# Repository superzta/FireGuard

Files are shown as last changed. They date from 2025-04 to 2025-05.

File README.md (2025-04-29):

# FireGuard: Automated Fire Detection and Monitoring System

FireGuard is an intelligent fire detection and monitoring system designed to proactively identify fire hazards using thermal imaging technology and provide real-time alerts through a web interface.

## System Overview

FireGuard consists of three main components:
- **Hardware**: An embedded system built on AVR microcontroller with thermal imaging camera, stepper motors for scanning, and other sensors
- **Firmware**: C code running on the AVR microcontroller
- **Web Interface**: Python Flask server and responsive web UI for monitoring and control

## System Features

- **360° Thermal Scanning**: Automated patrol mode that continuously scans the environment
- **High-Precision Fire Detection**: Uses the MLX90640 thermal imaging sensor to detect heat signatures
- **Real-time Monitoring**: Web interface displays temperature data and fire detection status
- **Automatic Targeting**: When a potential fire is detected, the system locks onto the target for monitoring
- **Distance Measurement**: Uses ultrasonic sensor to measure distance to the fire
- **Alert System**: Visual and audible alerts through LCD display and buzzer
- **Remote Control**: Web interface allows remote testing and system reset

## Hardware Components

### Sensors
- **MLX90640 Thermal Camera**: 32x24 IR array thermal imaging sensor (I²C)
- **HC-SR04 Ultrasonic Sensor**: Measures distance to fire
- **16x2 LCD Display**: Provides status information

### Actuators
- **Bipolar Stepper Motors (x2)**: For horizontal and vertical scanning movements
- **Servo Motor**: For fine adjustment of thermal camera position
- **Buzzer**: For audible fire alerts

### Microcontroller
- **AVR ATmega328P**: Main processing unit running at 7.3728MHz

### Connectivity
- **UART-to-USB Converter**: For communication with the web interface (230400 baud)

## Circuit Connections

### MLX90640 Thermal Camera
- SDA → PC4 (AVR I²C Data)
- SCL → PC5 (AVR I²C Clock)
- VCC → 3.3V
- GND → GND

### Stepper Motors (using EasyDriver)
- STEP_PIN_BTM → PC1 (Bottom stepper step control)
- STEP_PIN_TOP → PC2 (Top stepper step control)
- DIR_PIN → PC3 (Direction control for both steppers)
- VCC → 5V
- GND → GND

### Ultrasonic Sensor (HC-SR04)
- TRIG → PD6
- ECHO → PD7
- VCC → 5V
- GND → GND

### LCD Display (16x2)
- RS → PB0
- E → PB1
- D4 → PB2
- D5 → PB3
- D6 → PB4
- D7 → PB5
- VCC → 5V
- GND → GND

### Buzzer
- Signal → PD5
- GND → GND

### UART Connection
- TX → PD1
- RX → PD0
- Connected to computer via USB-to-UART adapter

## Software Architecture

### Firmware (AVR C)
- **FireGuard.c**: Main program logic
- **I2C.c/h**: Communication with MLX90640 thermal camera
- **stepper.c/h**: Stepper motor control for scanning
- **servo.c/h**: Servo motor control for fine positioning
- **ultrasonic.c/h**: Distance measurement
- **buzzer.c/h**: Alert system
- **lcd.c/h**: Display interface

### Web Interface
- **server.py**: Flask server that handles serial communication and API endpoints
- **FireGuard.html**: Responsive web UI with real-time data visualization
- **assets/**: CSS, JavaScript, and image resources

## Installation and Setup

### Firmware
1. Connect the AVR programmer to your computer
2. Navigate to the Firmware directory
3. Compile and upload using the included Makefile:
   ```bash
   cd FireGuard/Firmware/src
   make
   make flash
   ```

### Web Interface
1. Install Python 3.7 or higher
2. Install required packages:
   ```bash
   cd FireGuard/App
   pip install -r requirements.txt
   ```
3. Connect the FireGuard hardware via USB
4. Run the server:
   ```bash
   python server.py
   ```
5. Open a web browser and navigate to http://localhost:3000

## Troubleshooting

### Serial Connection Issues
- The default serial port is `/dev/cu.usbserial-A101167E`. If your system uses a different port, modify the `specific_port` variable in `server.py`
- Ensure the baud rate is set to 230400
- Check USB connections and drivers

### Temperature Sensor Issues
- The MLX90640 requires a warm-up period of approximately 10 seconds
- Ensure proper I²C connections and address (0x33)

### Motor Movement Issues
- Check stepper motor connections and power supply
- Verify the EasyDriver configuration (microstepping, current limiting)

## Future Enhancements

- Integration with smart home systems (HomeKit, Google Home)
- Cloud connectivity for remote monitoring
- Machine learning for improved fire detection accuracy
- Automatic fire suppression capabilities

## License

This project is licensed under the MIT License - see the LICENSE file for details.

## Contributors
- Owen Zeng
- Leikhang Xiong
- Robert Zhang

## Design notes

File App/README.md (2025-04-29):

# FireGuard Web Interface

This web application provides a user interface for the FireGuard fire detection system. It connects to the FireGuard hardware via serial communication and displays real-time fire detection data.

## Features

- Real-time monitoring of fire detection status
- Temperature data visualization with heat map
- Fire alerts with detailed information
- Remote system test and reset capabilities

## Prerequisites

- Python 3.7 or higher
- FireGuard hardware with firmware installed
- USB connection to the FireGuard device

## Installation

### Using the Setup Scripts (Recommended)

#### On macOS/Linux:

```bash
cd /path/to/FireGuard/App
chmod +x setup.sh
./setup.sh
```

#### On Windows:

```cmd
cd \path\to\FireGuard\App
setup.bat
```

### Manual Installation

1. Create a virtual environment:

```bash
# macOS/Linux
python3 -m venv venv
source venv/bin/activate

# Windows
python -m venv venv
venv\Scripts\activate
```

2. Install the required packages:

```bash
pip install -r requirements.txt
```

## Running the Application

1. Make sure the FireGuard hardware is connected to your computer via USB.

2. Activate the virtual environment (if not already activated):

```bash
# macOS/Linux
source venv/bin/activate

# Windows
venv\Scripts\activate
```

3. Run the server:

```bash
python server.py
```

4. Open a web browser and go to http://localhost:3000

## Usage

The web interface automatically connects to the FireGuard hardware when started. It will display:

- **All Clear**: When no fire is detected
- **Fire Alert**: When a fire is detected, showing the temperature matrix as a heat map
- **Fire Extinguished**: When a fire has been detected and subsequently extinguished

### Controls

- **Run Test**: Simulates a fire detection event (useful for testing without actual fire)
- **System Check**: Performs a system self-test
- **Emergency Override**: For manually controlling the system during a fire event
- **Reset System**: Resets the system after a fire has been extinguished

### Running Without Hardware

For testing and demonstration purposes, you can:

1. Start the Python server without hardware connected - it will provide simulated data through the test endpoint
2. Use the "Run Test" button to simulate a fire detection event

## Troubleshooting

If the web interface shows "Disconnected" in the status indicator:

1. Make sure the FireGuard hardware is properly connected via USB
2. Check that the correct serial port is being detected (the server prints this information on startup)
3. Try manually specifying your serial port by editing the `specific_port` variable in `server.py`
4. Restart the server with the hardware connected
5. If problems persist, check the Arduino IDE's serial monitor to verify the hardware is working correctly

## Developer Information

- The server runs on Flask and communicates with the web interface via JSON API endpoints at port 3000
- Real-time updates are implemented using AJAX polling
- Temperature matrix visualization uses CSS grid and dynamic color mapping

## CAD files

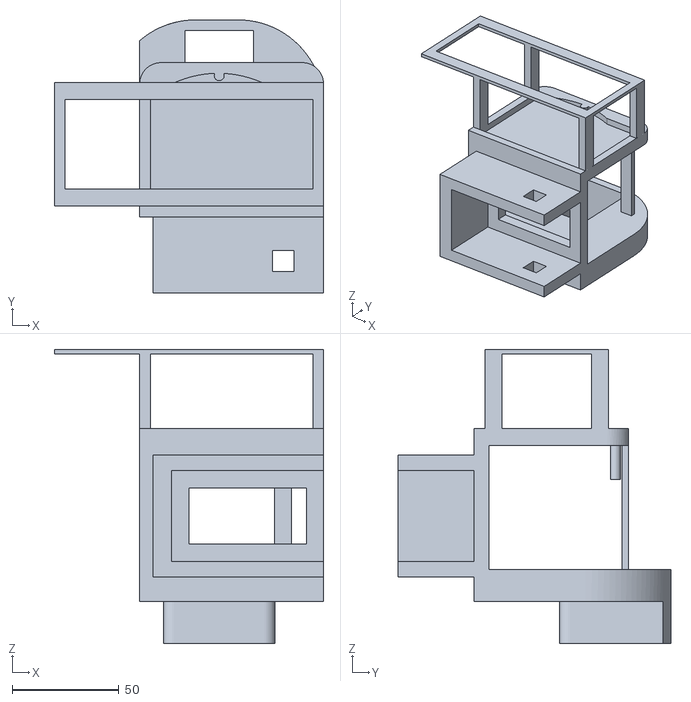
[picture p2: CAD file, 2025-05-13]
CAD/launcher_turret_draft1 v59.stl
126.1 x 127.9 x 137.7

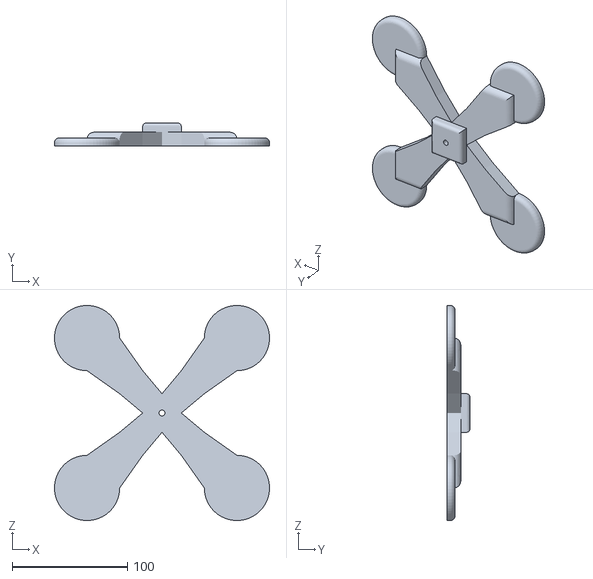
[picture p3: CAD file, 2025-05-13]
CAD/launcher_base_draft1 v13.stl
186.5 x 20.0 x 186.5

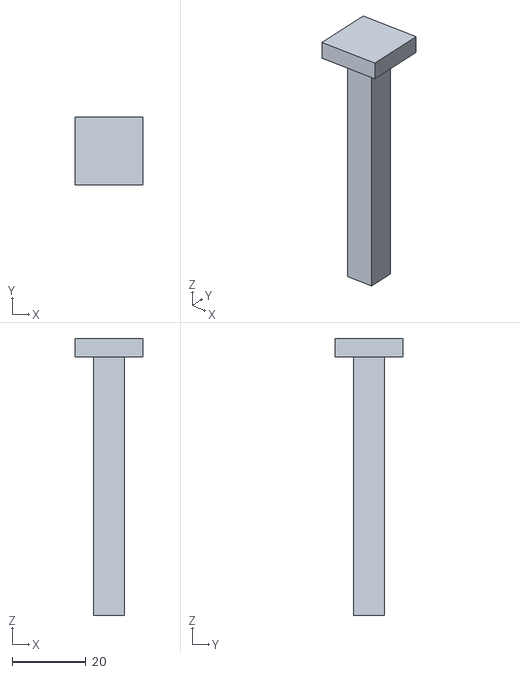
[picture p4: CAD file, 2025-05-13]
CAD/launcher_pin v2.stl
18.5 x 18.5 x 75.0

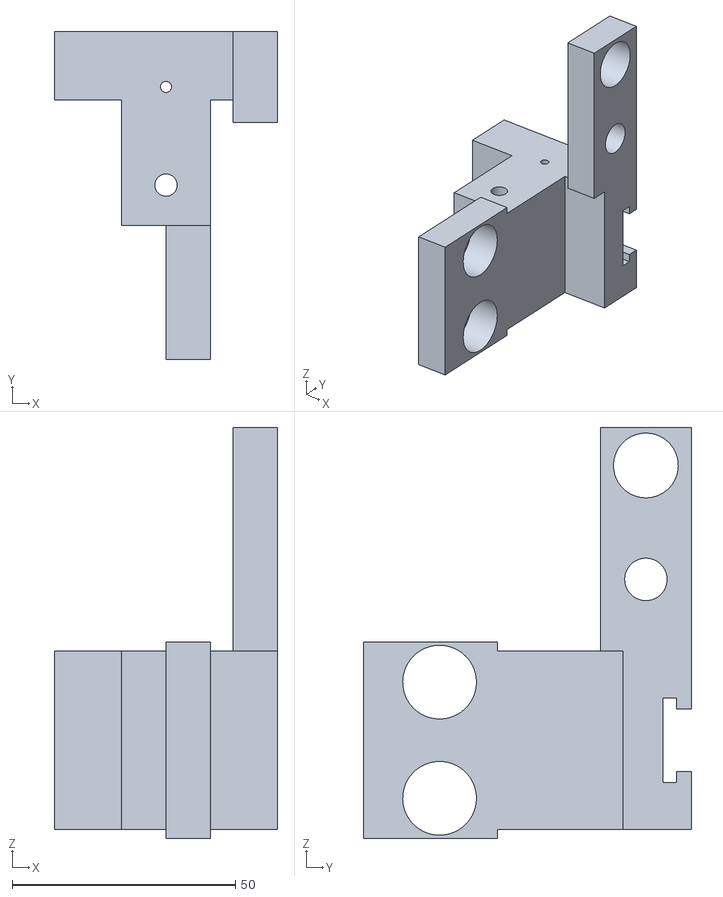
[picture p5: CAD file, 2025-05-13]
CAD/Launcher_mount_draft1 v21.stl
50.0 x 73.4 x 92.0

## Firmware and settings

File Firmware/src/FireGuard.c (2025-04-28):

#include <avr/io.h>
#include <util/delay.h>
#include <stdlib.h>
#include <stdio.h>
#include <avr/wdt.h>
#include <stdint.h>
#include <stdbool.h>

#include "I2C.h"
#include "stepper.h"
#include "servo.h"
#include "ultrasonic.h"
#include "buzzer.h"
#include "lcd.h"

#ifndef F_CPU
#define F_CPU 7372800UL
#endif

#define BAUD_RATE 230400

// Scanning motion parameters - easily changeable
#define SCAN_RANGE_STEPS 800   // 120 degrees of motion (approximately)
#define STEPS_PER_CHECK 20     // Check temperature every 20 steps
#define MOTOR_STEP_DELAY 10    // Milliseconds between steps to control speed

// Threshold temperature for fire detection (in centidegrees)
#define FIRE_THRESHOLD 5000  // 50.00°C

// Position constraints for fire confirmation (helps prevent false positives)
#define FIRE_COL_MIN 13
#define FIRE_COL_MAX 15

// Buzzer parameters for fire alert
#define BUZZER_ON_TIME 3000   // 3 second buzz
#define BUZZER_OFF_TIME 500   // 0.5 second silence

// For reusing buffers
char buffer[48];

int main(void) {
    // Disable watchdog
    MCUSR = 0;
    wdt_disable();
    
    // Initialize UART
    serial_init((F_CPU / 16 / BAUD_RATE) - 1);
    
    // Send welcome message
    serial_println("FireGuard System Initializing...");
    
    // Initialize thermal sensor
    i2c_init();
    _delay_ms(100);
    
    int result = mlx90640_init();
    if (result != 0) {
        sprintf(buffer, "Thermal sensor init failed: %d", result);
        serial_println(buffer);
    } else {
        serial_println("Thermal sensor initialized successfully");
    }
    
    // Initialize stepper motor
    setup_pins();
    
    // Start with counter-clockwise direction (default)
    set_stepper_direction(false);

    // Initialize servo
    servo_init();
    
    // Initialize ultrasonic sensor
    ultrasonic_init();
    
    // Initialize buzzer
    buzzer_init();

    // Initialize LCD
    lcd_init();
    // hide the cursor
    lcd_writecommand(0x0c);
    
    // Main variables
    int16_t current_step = 0;
    bool scanning_forward = false;  // Start counter-clockwise
    bool fire_detected = false;
    
    serial_println("Starting fire detection patrol with scanning motion...");
    
    // Main loop
    while (1) {
        //patrol until fire detected
        while (!fire_detected) {
            // Step the motor once in current direction
            move_bottom_stepper_once();
            _delay_ms(MOTOR_STEP_DELAY);
            
            current_step++;
            
            // Check if we need to reverse direction
            if (current_step >= SCAN_RANGE_STEPS) {
                // Change direction
                scanning_forward = !scanning_forward;
                set_stepper_direction(scanning_forward);
                
                // Reset step counter
                current_step = 0;
                
                // Log direction change
                if (scanning_forward) {
                    serial_println("Changing direction: Clockwise");
                } else {
                    serial_println("Changing direction: Counter-clockwise");
                }
            }
            
            // Check temperature periodically
            if (current_step % STEPS_PER_CHECK == 0) {
                // Read thermal data from sensor
                result = mlx90640_read_center_region();
                
                // Process the reading if successful
                if (result == 0) {
                    // Print status update
                    int16_t int_part = max_temp / 100;
                    uint8_t frac_part = abs(max_temp) % 100;
                    
                    sprintf(buffer, "Pos: %d/%d | Max: %d.%02d°C at [%d][%d]", 
                            current_step, SCAN_RANGE_STEPS, int_part, frac_part, 
                            max_row_pos, max_col_pos);
                    serial_println(buffer);

                    // If max temp is greater than threshold set the btm stepper to move towards
                    if (max_temp > FIRE_THRESHOLD) {
                        // Move the stepper left or right so that the col pos is about 0-3
                        if (max_col_pos < FIRE_COL_MIN) {
                            // we always want it to move counter clockwise
                            // first check if the current direction is counter clockwise
                            if (!scanning_forward) { // If the stepper is moving counter clockwise meaning the device is moving clockwise
                                // if it is ignore and keep moving
                                serial_println("No need to change direction, keep moving");
                            } else {
                                // if it is, move right
                                // Change direction to right
                                scanning_forward = false;
                                set_stepper_direction(scanning_forward);
                                serial_println("Changing direction to right");
                            }
                        }
                    }


                    // Check if fire detected (temp > threshold and in target columns)
                    if (max_temp > FIRE_THRESHOLD && 
                        max_col_pos >= FIRE_COL_MIN && max_col_pos <= FIRE_COL_MAX) {
                        
                        fire_detected = true;
                        
                        // Detailed fire detection message
                        sprintf(buffer, "FIRE DETECTED! Temp: %d.%02d°C at [%d][%d]", 
                                int_part, frac_part, max_row_pos, max_col_pos);
                        serial_println(buffer);
                    }
                } else {
                    serial_println("Error reading thermal data");
                    lcd_moveto(0, 0);
                    // clear the screen
                    lcd_writecommand(0x01);
                    lcd_stringout("Error reading thermal data");
                }
            }
        }
        
        // Fire alert mode - motor stopped, monitoring continues
        serial_println("Motor stopped - FIRE ALERT MODE");
        lcd_moveto(0, 0);
        // clear the screen
        lcd_writecommand(0x01);
        lcd_stringout("Motor stopped - FIRE ALERT MODE");
        
        // Keep monitoring in alert mode if fire is detected
        while (fire_detected) {
            result = mlx90640_read_center_region();
            
            if (result == 0) {
                int16_t int_part = max_temp / 100;
                uint8_t frac_part = abs(max_temp) % 100;
                
                sprintf(buffer, "Alert! Temp: %d.%02d°C at [%d][%d]", 
                        int_part, frac_part, max_row_pos, max_col_pos);
                serial_println(buffer);

                // clear the screen
                lcd_writecommand(0x01);
                lcd_moveto(0, 0);
                lcd_stringout("Alert! Temp: ");
                lcd_stringout(buffer);
                // print out the whole arrat of temp values in a matrix form
                // use the print_center_matrix function to print the array
                print_center_matrix();

                // Measure distance with ultrasonic sensor
                float distance = measure_distance();
                
                // Display distance
                dtostrf(distance, 6, 2, buffer);
                serial_print("Distance to fire: ");
                serial_print(buffer);
                serial_println(" cm");

                // Move to second line
                lcd_moveto(1, 0);
                lcd_stringout("Distance: ");
                lcd_stringout(buffer);
                lcd_stringout(" cm");
                
                // Play the warning sound
                buzzer_warning();

                // Set servo to 0 and 105 degrees
                set_servo_degree(0);
                _delay_ms(1000);
                set_servo_degree(105);
                _delay_ms(1000);
            }

            // Check if fire is detected
            if (max_temp > FIRE_THRESHOLD && 
                max_col_pos >= FIRE_COL_MIN && max_col_pos <= FIRE_COL_MAX) {
                fire_detected = true;
            } else {
                fire_detected = false;
                serial_println("Fire alert mode ended");
                lcd_moveto(0, 0);
                // clear the screen
                lcd_writecommand(0x01);
                lcd_stringout("Fire alert mode ended");
            }
            
            // Update at 1Hz in alert mode
            _delay_ms(1000);
        }
    }
    
    return 0;
}

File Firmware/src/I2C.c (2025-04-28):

#include <avr/io.h>
#include <util/delay.h>
#include <stdlib.h>
#include <stdio.h>
#include <string.h>
#include <avr/wdt.h>
#include <math.h>
#include <stdint.h>

// Include our header
#include "I2C.h"

#ifndef F_CPU
#define F_CPU 7372800UL
#endif

#define BAUD_RATE 230400

// I2C and MLX90640 definitions
#define MLX90640_I2CADDR 0x33
#define MLX90640_DEVICEID1 0x0F2D
#define MLX90640_CHESS 1
#define MLX90640_INTERLEAVED 0
#define TA_SHIFT 8

// Frame size
#define MLX90640_WIDTH 32
#define MLX90640_HEIGHT 24

// // Center 8x8 region
// #define CENTER_SIZE 8
// #define CENTER_START_ROW ((24 - CENTER_SIZE) / 2)
// #define CENTER_START_COL ((32 - CENTER_SIZE) / 2)

// Center 16x16 region
#define CENTER_SIZE 16
#define CENTER_START_ROW ((24 - CENTER_SIZE) / 2)
#define CENTER_START_COL ((32 - CENTER_SIZE) / 2)

// I2C bit manipulation macros
#define I2C_SDA_HIGH() DDRC &= ~(1 << PC4)
#define I2C_SDA_LOW() do { DDRC |= (1 << PC4); PORTC &= ~(1 << PC4); } while(0)
#define I2C_SCL_HIGH() do { DDRC &= ~(1 << PC5); _delay_us(5); } while(0)
#define I2C_SCL_LOW() do { DDRC |= (1 << PC5); PORTC &= ~(1 << PC5); _delay_us(5); } while(0)
#define I2C_SDA_READ() (PINC & (1 << PC4))

// Global variables - MEMORY OPTIMIZED
int16_t center_data[CENTER_SIZE][CENTER_SIZE]; // Keep this for the 8x8 matrix
int16_t max_temp;
uint8_t max_row_pos;  // Position of max temperature
uint8_t max_col_pos;
uint8_t i2c_initialized = 0;
// Shared buffer for string operations
char string_buffer[8]; 

// Serial communication functions
void serial_init(unsigned short ubrr) {
    UBRR0H = (unsigned char)(ubrr >> 8); 
    UBRR0L = (unsigned char)ubrr;        
    UCSR0B = (1 << TXEN0) | (1 << RXEN0); 
    UCSR0C = (3 << UCSZ00);              
}

void serial_out(char ch) {
    while (!(UCSR0A & (1 << UDRE0))); 
    UDR0 = ch; 
}

char serial_in() {
    while (!(UCSR0A & (1 << RXC0))); 
    return UDR0; 
}

void serial_print(const char *str) {
    for (int i = 0; str[i] != '\0'; i++) {
        serial_out(str[i]);
    }
}

void serial_println(const char *str) {
    serial_print(str);
    serial_out('\r');
    serial_out('\n');
}

// Print fixed-point temperature (value is temp * 100)
void print_temp(int16_t value) {
    char buffer[16];
    int16_t int_part = value / 100;
    uint8_t frac_part = (uint8_t)((value < 0 ? -value : value) % 100);
    
    sprintf(buffer, "%d.%02d", int_part, frac_part);
    serial_print(buffer);
}

// I2C implementation
void i2c_stop(void);  // Forward declaration

void i2c_init() {
    if (i2c_initialized) return;
    
    // Set SDA and SCL as inputs with pull-ups enabled
    DDRC &= ~((1 << PC4) | (1 << PC5));
    PORTC |= (1 << PC4) | (1 << PC5);
    _delay_ms(10);
    
    // Send a stop condition to reset the bus
    i2c_stop();
    
    i2c_initialized = 1;
}

void i2c_start() {
    I2C_SDA_HIGH();
    I2C_SCL_HIGH();
    _delay_us(5);
    I2C_SDA_LOW();
    _delay_us(5);
    I2C_SCL_LOW();
}

void i2c_stop() {
    I2C_SDA_LOW();
    _delay_us(5);
    I2C_SCL_HIGH();
    _delay_us(5);
    I2C_SDA_HIGH();
    _delay_us(5);
}

uint8_t i2c_write(uint8_t data) {
    uint8_t i, ack;
    
    for (i = 0; i < 8; i++) {
        if (data & 0x80)
            I2C_SDA_HIGH();
        else
            I2C_SDA_LOW();
            
        _delay_us(5);
        I2C_SCL_HIGH();
        _delay_us(5);
        I2C_SCL_LOW();
        data <<= 1;
    }
    
    I2C_SDA_HIGH();
    _delay_us(5);
    I2C_SCL_HIGH();
    _delay_us(5);
    
    ack = I2C_SDA_READ() ? 1 : 0;
    I2C_SCL_LOW();
    
    return ack;
}

uint8_t i2c_read(uint8_t ack) {
    uint8_t i, data = 0;
    
    I2C_SDA_HIGH();
    
    for (i = 0; i < 8; i++) {
        data <<= 1;
        I2C_SCL_HIGH();
        _delay_us(5);
        if (I2C_SDA_READ())
            data |= 1;
        I2C_SCL_LOW();
        _delay_us(5);
    }
    
    if (ack)
        I2C_SDA_LOW();
    else
        I2C_SDA_HIGH();
        
    _delay_us(5);
    I2C_SCL_HIGH();
    _delay_us(5);
    I2C_SCL_LOW();
    I2C_SDA_HIGH();
    
    return data;
}

// Optimized I2C read for MLX90640 - read only what we need
int mlx90640_i2c_read(uint8_t addr, uint16_t reg, uint16_t* data, uint8_t count) {
    int retries = 3;
    
    while (retries--) {
        i2c_start();
        
        if (i2c_write((addr << 1) & 0xFE)) {  // Write address
            i2c_stop();
            continue;
        }
        
        if (i2c_write(reg >> 8) || i2c_write(reg & 0xFF)) {  // Register address
            i2c_stop();
            continue;
        }
        
        i2c_start();  // Restart
        
        if (i2c_write((addr << 1) | 0x01)) {  // Read address
            i2c_stop();
            continue;
        }
        
        // Read data
        for (uint8_t i = 0; i < count; i++) {
            uint16_t msb = i2c_read(1);  // ACK
            uint16_t lsb = i2c_read(i < count - 1);  // NACK on last byte
            data[i] = (msb << 8) | lsb;
        }
        
        i2c_stop();
        return 0;  // Success
    }
    
    return -1;  // Failure
}

// Optimized I2C write for MLX90640
int mlx90640_i2c_write(uint8_t addr, uint16_t reg, uint16_t data) {
    int retries = 3;
    
    while (retries--) {
        i2c_start();
        
        if (i2c_write((addr << 1) & 0xFE)) {  // Write address
            i2c_stop();
            continue;
        }
        
        if (i2c_write(reg >> 8) || i2c_write(reg & 0xFF)) {  // Register address
            i2c_stop();
            continue;
        }
        
        if (i2c_write(data >> 8) || i2c_write(data & 0xFF)) {  // Data
            i2c_stop();
            continue;
        }
        
        i2c_stop();
        return 0;  // Success
    }
    
    return -1;  // Failure
}

// Check if data is ready and clear flag
int mlx90640_check_data_ready() {
    uint16_t statusReg;
    int retry = 10;
    
    // Wait for data ready flag
    while (retry--) {
        if (mlx90640_i2c_read(MLX90640_I2CADDR, 0x8000, &statusReg, 1) != 0) {
            continue;
        }
        
        if (statusReg & 0x0008) {  // Data ready flag
            // Clear flag
            mlx90640_i2c_write(MLX90640_I2CADDR, 0x8000, 0x0030);
            return 0;  // Data ready
        }
        
        _delay_ms(10);
    }
    
    return -1;  // Timeout
}

// Read a single pixel value directly
int16_t read_pixel_value(uint8_t row, uint8_t col) {
    uint16_t pixelAddr = 0x0400 + ((row * MLX90640_WIDTH + col) * 2);
    uint16_t rawValue;
    
    if (mlx90640_i2c_read(MLX90640_I2CADDR, pixelAddr, &rawValue, 1) != 0) {
        return 0;  // Error
    }
    
    // Convert raw value to temperature (simplified conversion)
    // The actual MLX90640 has a more complex conversion algorithm
    // This is a basic linear approximation
    int16_t value = ((int16_t)rawValue * 10) - 1000; // Scale and offset
    
    return value;
}
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

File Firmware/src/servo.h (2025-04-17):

#ifndef SERVO_H
#define SERVO_H

#include <stdint.h>


#define SERVO_MIN_PULSE 750    // in microseconds
#define SERVO_MAX_PULSE 2250   // in microseconds
#define PWM_PERIOD_US    16000 // 16ms typical servo period

#define PRESCALER 64
#define F_CPU 7372800UL
#define TIMER_TICK_US (PRESCALER * 1.0 / (F_CPU / 1000000UL))  // 4us per tick

#define SERVO_MIN_OCR (SERVO_MIN_PULSE / TIMER_TICK_US)  // = 750 / 4 = ~188
#define SERVO_MAX_OCR (SERVO_MAX_PULSE / TIMER_TICK_US)  // = 2250 / 4 = ~563

// Stepper motor functions
void servo_init();
void set_servo_degree(uint8_t degree);

#endif /* SERVO_H */ 

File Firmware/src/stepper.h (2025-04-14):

#ifndef STEPPER_H
#define STEPPER_H

#include <stdbool.h>

// EasyDriver pin mappings
#define STEP_PIN_BTM    PC1
#define STEP_PIN_TOP    PC2
#define DIR_PIN         PC3
#define STEP_DELAY_US   2000

// Stepper motor functions
void setup_pins(void);
void set_stepper_direction(bool move_clockwise);
void move_top_stepper(bool top_step);
void move_bottom_stepper_once(void);

#endif /* STEPPER_H */ 

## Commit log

2025-04-14 add logic for turning and find
    [Untitled Sketch.fzz]
2025-04-17 add servo
2025-05-13 Added CAD files
    [Launcher_mount_draft1 v21.stl, launcher_base_draft1 v13.stl, launcher_pin v2.stl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]
